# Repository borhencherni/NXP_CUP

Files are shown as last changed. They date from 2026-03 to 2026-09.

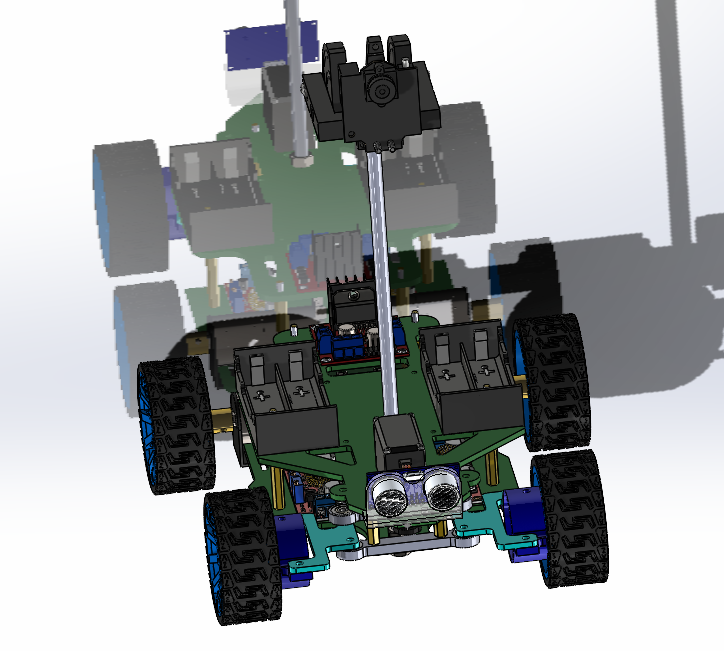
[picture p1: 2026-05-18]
Mechanical design of the robot.png

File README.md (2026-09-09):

**NXP Cup Robot**  
This repository contains the software, electronics, mechanical references, and documentation for the NXP Cup lane-following competition robot.  
   
 The current implementation is centered on two main embedded targets:  
- a Teensy 4.0 control unit that handles line tracking, steering, motor control, and telemetry generation  
- an ESP32 interface board that provides a web dashboard, manual drive controls, and live trajectory visualization  
**Project Overview 🤖**  
The robot is designed to follow a track as consistently and efficiently as possible while remaining debuggable during development.  
   
 The software is organized so that the core logic is separated into small header/source modules, making the control flow easier to maintain and inspect.  
   
 The goal of this document is to describe the robot, the role of each code part, and the current development phases in a way that matches the actual project structure.  
**System Architecture ⚙️**  
**Teensy 4.0 🧠**  
The Teensy is the main real-time controller. It is responsible for:  
- reading the Pixy2 line camera data  
- normalizing and fusing detected line vectors  
- computing a lookahead point for steering  
- applying PID-style steering correction  
- detecting lane sides and special line patterns  
- driving the motors and steering servo  
- reading the ultrasonic distance sensor  
- sending telemetry packets to the ESP32 over UART  
The Teensy code is organized into focused modules under NXPcup/include and NXPcup/src/teensy:  
- teensy_config.h for constants, pins, and tuning values  
- teensy_state.h and teensy_state.cpp for shared robot state  
- teensy_motors.h and teensy_motors.cpp for motor and servo output  
- teensy_sensors.h and teensy_sensors.cpp for ultrasonic sensing  
- teensy_vision.h and teensy_vision.cpp for Pixy2 processing and steering logic  
- main_teensy.cpp as the control entrypoint  
**ESP32 Interface 🌐**  
The ESP32 acts as the operator interface and telemetry gateway. It is responsible for:  
- receiving telemetry packets from the Teensy through UART  
- exposing a Wi-Fi access point  
- serving a browser-based control dashboard  
- sending manual drive commands back to the Teensy  
- drawing the robot trajectory in real time from received points  
The ESP32 code is organized into:  
- esp_config.h for UART and access point settings  
- esp_telemetry.h and esp_telemetry.cpp for packet parsing, point history, and command forwarding  
- esp_web.h and esp_web.cpp for the HTML interface and HTTP routes  
- main_esp.cpp as the entrypoint  
**Control Logic 🧭**  
The Teensy control loop follows a clear sequence:  
1. Read all Pixy2 line features  
2. Normalize line vector direction  
3. Fuse valid vectors into a single motion estimate  
4. Normalize the fused vector  
5. Compute an adaptive lookahead point  
6. Convert the lookahead error into steering correction  
7. Apply lane-side correction when only one side of the track is visible  
8. Clamp and smooth the servo command  
9. Drive the motors  
10. Send telemetry to the ESP32  
The telemetry packet format is:  
D,vx,vy,steeringangle,servoangle  
The ESP32 manual command format is:  
C,<command>  
Where the current commands are:  
- F for forward  
- B for backward  
- L for left  
- R for right  
- S for stop  
The current control strategy focuses on lane following and smooth steering.  
   
 The robot can be further developed by adding velocity regulation and speed profiling, in the style of the code asservissement vitesse approach, to keep the speed more stable across straights, curves, and transitions.  
**Phases Of Working 🔄**  
**1. Perception**  
The Pixy2 camera runs in line-tracking mode and the Teensy extracts track geometry from the visible vectors.  
   
 This phase focuses on identifying the path, rejecting noise, and understanding sharp turns, lane boundaries, and horizontal markers.  
**2. Motion Estimation**  
The detected vectors are filtered and fused into a single direction estimate.  
   
 A lookahead point is then computed so the robot can react smoothly on straights and more aggressively in curves.  
**3. Steering And Drive Control**  
The steering output is computed from the lookahead error and adjusted with PID-style terms.  
   
 The motor speed and servo angle are then constrained to keep motion stable.  
**4. Telemetry And Debugging**  
The Teensy sends live telemetry to the ESP32 so the robot can be observed while running.  
   
 This data includes vector direction, steering output, and servo angle.  
**5. Operator Interface**  
The ESP32 hosts a browser dashboard with manual drive buttons and a live trace of the robot path.  
   
 The LED status indicator changes color based on whether telemetry is being received.  
**6. Mechanical And Electrical Integration**  
The CAD, PCB, and wiring notes are used to assemble the chassis, sensors, drivetrain, and electronics reliably.  
   
 This phase ties the software to the physical robot.  
**Mechanical Part 🛠️**  
The mechanical part covers the chassis, steering, drivetrain, and mounting system.  
   
 These references are useful for assembly, servicing, and mechanical debugging.  
**Robot Assembly**  
**Mechanical Design**  
**Electrical Part ⚡**  
The electrical part covers the wiring, PCB layout, power distribution, and interface hardware.  
   
 These elements support the sensors, controller, motor driver, and communication links.  
**System Schematic**  
**PCB Routing**  
**PCB Overview**  
**Validation Videos 🎥**  
The following videos are used to validate different layers of the system during development:  
- video for the robot completing one lap.mp4 for the robot completing one lap  
- video for the robot stopping when detecting the box.mp4 for the robot stopping test  
**Pins And Hardware Notes 📌**  
Current Teensy pin usage:  
- motor inputs: 22, 23, 6, 7  
- servo output: 8  
- ultrasonic trigger: 18  
- ultrasonic echo: 19  
The project uses:  
- Teensy 4.0 as the controller  
- Pixy2 in line mode  
- steering servo  
- H-bridge motor driver  
- ultrasonic distance sensor  
- ESP32 for telemetry and control UI  
**Web Interface 🖥️**  
The ESP32 dashboard uses a dark industrial theme based on black, white, and #AA0000 red accents.  
   
 It includes:  
- forward, backward, left, right, and stop buttons  
- a circular ESP badge with a connection LED  
- live telemetry readouts  
- a black canvas with a white trail showing the robot path in real time  
**Web Interface Preview**  
**Software Layout 💻**  
The main source folders are:  
- NXPcup/src/teensy for the Teensy 4.0 control code  
- NXPcup/src/esp for the ESP32 dashboard and UART bridge  
- NXPcup/include for shared headers and configuration  
- NXPcup/lib for legacy or reusable helper sources  
- notes for pinout and power notes  
- Mécanique for CAD and mechanical references  
**Code Roles 🧩**  
The code is split so each module has a clear role in the robot:  
- main_teensy.cpp runs the full real-time control loop and coordinates perception, steering, drive output, and telemetry  
- teensy_vision.cpp handles Pixy2 processing, vector fusion, lane detection, and steering computation  
- teensy_motors.cpp converts high-level speed commands into motor outputs and servo control  
- teensy_sensors.cpp reads the ultrasonic sensor used for distance checking  
- teensy_state.cpp stores the shared robot state used by the other Teensy modules  
- main_esp.cpp initializes the ESP32 system and connects the web dashboard to UART telemetry  
- esp_telemetry.cpp parses telemetry packets, stores path points, and forwards manual commands  
- esp_web.cpp serves the browser interface, controls the buttons, and draws the live ride trace  
**Development Note 🚀**  
The robot can also be extended with velocity regulation and speed profiling in the style of code asservissement vitesse to stabilize motion across straights, curves, and transitions.  
**Power And Wiring Notes 🔌**  
The project notes indicate the following supply plan:  
- Teensy: 5V  
- camera: external 5V  
- servo: external 5V  
- motors: 12V  
- ultrasonic sensor: 3.3V  
- logic and power grounds must be shared where required  
**Build And Run 🏗️**  
The PlatformIO project is configured for the Teensy environment in NXPcup/platformio.ini.  
   
 Typical workflow:  
1. open the NXPcup folder in PlatformIO or VS Code  
2. build the Teensy environment  
3. upload to the Teensy board  
4. power the ESP32 and open the Wi-Fi dashboard  
5. watch the telemetry stream and path trace in the browser  
Example build command:  
cd NXPcup  
 platformio run -e teensy40  
   
**Resources 📚**  
- [Enseirb NXP Cup 2019 ](https://github.com/Enseirb-NXP-Cup-2019/cars/blob/master/src/Arduino/suivi_piste.ino "https://github.com/Enseirb-NXP-Cup-2019/cars/blob/master/src/Arduino/suivi_piste.ino")  
- [Enseirb NXP Cup 2019 website](https://github.com/Enseirb-NXP-Cup-2019/nxpcup.enseirb.github.io?tab=readme-ov-file "https://github.com/Enseirb-NXP-Cup-2019/nxpcup.enseirb.github.io?tab=readme-ov-file")  
- [Electromaker NXP Cup project](https://www.electromaker.io/project/view/nxp-cup-project "https://www.electromaker.io/project/view/nxp-cup-project")  
- [NXP-CUP-FINALS](https://github.com/aminebensaid66/NXP-CUP-FINALS "https://github.com/aminebensaid66/NXP-CUP-FINALS")  
**Notes 📝**  
This documentation reflects the current modularized Teensy and ESP32 codebase.  
   
 It is intended to help with debugging, maintenance, and competition preparation by keeping the code paths, hardware roles, and project assets in one place.  
   
   
 This work was done by the team members :  
   
 - Borhen CHERNI  
 - Mahmoud SOUABNI  
 - Meher LAHWAR

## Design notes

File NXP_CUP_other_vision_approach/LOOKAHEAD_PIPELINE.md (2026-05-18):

# From (vx, vy) to (px, py) — Lookahead Pipeline

## Context

The Pixy2 camera sees the line on the track and returns a set of vectors.
After filtering, fusing, and normalizing those vectors, we end up with a
single **unit vector (vx, vy)** that represents the direction of the line
ahead of the car.

The goal of this pipeline is to convert that direction into a **target point
(px, py)** in the camera frame — a point that the car should aim for.

---

## Step 1 — What is (vx, vy) exactly?

After `normalizeFusedVector()`, the vector (vx, vy) is a **unit vector**:

```
√(vx² + vy²) = 1   always
```

This means the length is always exactly 1. Normalization throws away the
length information and keeps only the **direction** of the line.

### What the values mean

```
vx =  0.0   → line goes perfectly straight up     → no horizontal component
vx =  1.0   → line goes perfectly horizontal right → maximum right turn
vx = -1.0   → line goes perfectly horizontal left  → maximum left turn

vy = -1.0   → line goes straight up (away from car) → normal forward direction
vy =  0.0   → line is perfectly horizontal           → extreme case
```

> In Pixy2 coordinates, y increases downward. So a line going away from
> the car (upward in the frame) has a negative vy after normalization.

### Geometric interpretation

Since (vx, vy) is a unit vector, it can be written as:
```
vx = cos(θ)
vy = sin(θ)
```
where θ is the angle of the line relative to the horizontal axis.

If you walk **1 unit** in the direction (vx, vy), you move exactly:
- `vx` units horizontally
- `vy` units vertically

---

## Step 2 — What is the lookahead distance L?

Instead of steering toward the nearest point on the line, we look **ahead**
by a distance L along the direction vector — like a driver looking further
down the road rather than at the front bumper.

L is a **fraction of the frame size** — a number between 0 and 1 that
represents what percentage of the frame we want to look ahead.

```
L = 0.4  →  look 40% of the frame ahead  (close, reactive)
L = 0.9  →  look 90% of the frame ahead  (far, smooth)
```

In actual pixels:
```
L × frameWidth  = L × 78  pixels of horizontal reach
L × frameHeight = L × 51  pixels of vertical   reach
```

---

## Step 3 — Adaptive lookahead (computing L)

L is not fixed — it adapts based on how curved the road is.

### Why adaptive?

- On a **straight line** → look far ahead (smooth, stable steering)
- On a **sharp turn**   → look close   (reactive, don't overshoot the corner)

### Computing curvature

```cpp
float curvature = fabsf(vx);
```

Since vx ∈ [-1, 1] after normalization:
- `vx = 0`  → line going straight → curvature = 0
- `vx = ±1` → line going sideways → curvature = 1

`fabsf` takes the absolute value because we only care about *how much*
curvature there is, not which direction (left or right).

### The interpolation formula

```cpp
L = L_MAX - curvature * (L_MAX - L_MIN);
```

Let's break this down. First compute the constant part:
```
L_MAX - L_MIN = 0.9 - 0.4 = 0.5
```

So the formula simplifies to:
```
L = 0.9 - curvature × 0.5
```

| curvature | L | meaning |
|---|---|---|
| 0.0 | 0.9 - 0×0.5 = **0.9** | straight → look far |
| 0.5 | 0.9 - 0.5×0.5 = **0.65** | medium turn |
| 1.0 | 0.9 - 1×0.5 = **0.4** | sharp turn → look close |

As curvature increases from 0 to 1, L decreases linearly from 0.9 to 0.4.
This is called **linear interpolation** — the output changes at a constant
rate as the input changes.

Visually:
```
curvature:  0 ──────────── 0.5 ──────────── 1
         L=0.9             0.65          L=0.4
         (far)                          (close)
```

---

## Step 4 — Computing the pixel displacement (step_x, step_y)

Now that we have the direction (vx, vy) and the lookahead distance L,
we compute how many pixels to move from the car's position.

```
step_x = vx × L × frameWidth
step_y = vy × L × frameHeight
```

### Reading the formula

Read it as two multiplications in sequence:

```
L × frameWidth  →  total pixels we want to travel
                   e.g. 0.75 × 78 = 58.5 pixels total

× vx            →  of those 58.5 pixels, how many go horizontally
                   e.g. × 0.3 = 17.5 pixels to the right
```

The same logic applies for step_y with frameHeight.

### Why multiply x and y by different frame dimensions?

The frame is **not square** (78 × 51 pixels). If we used the same scale
for both axes, a vector pointing at 45° in real life would appear at a
wrong angle in pixel space.

By multiplying x by `frameWidth` and y by `frameHeight` separately, we
correctly stretch the unit vector into the actual pixel coordinate space
of the camera frame.

Example with a 45° line:
```
vx = 0.707,  vy = -0.707   (45° diagonal, unit vector)
L  = 0.75

step_x = 0.707 × 0.75 × 78 = 41.4 pixels right
step_y = 0.707 × 0.75 × 51 = 27.1 pixels up
```

Notice step_x ≠ step_y even though vx = vy in magnitude — because 78 ≠ 51.

---

## Step 5 — Computing the target point (px, py)

The car is always at the **bottom center** of the frame:
```
car_x = frameWidth  / 2 = 78 / 2 = 39   (horizontal center)
car_y = frameHeight      = 51            (bottom of frame)
```

The target point is simply the car's position plus the pixel displacement:
```cpp
px = frameWidth  / 2.0f + vx * L * frameWidth;
py = frameHeight         + vy * L * frameHeight;
```

Which expands to:
```
px = 39 + step_x
py = 51 + step_y
```

### Concrete example

Line going slightly to the right:
```
vx =  0.30,  vy = -0.95   (mostly forward, slightly right)
L  =  0.75   (medium lookahead)

step_x =  0.30 × 0.75 × 78 =  17.6 pixels right
step_y = -0.95 × 0.75 × 51 = -36.4 pixels up

px = 39 + 17.6 = 56.6
py = 51 - 36.4 = 14.6
```

The target point is at (56.6, 14.6) — upper right area of the frame,
which makes sense for a slight right curve ahead.

Visual representation:
```
(0,0)─────────────────────(78,0)
  │                          │
  │       * (56.6, 14.6)     │  ← target point
  │      ↗                   │
  │     ↗  L steps            │
  │    ↗   along vector       │
  │   ↗                      │
(0,51)────────●──────────(78,51)
             (39,51) ← car position
```

---

## Step 6 — Why only px is used for steering

After computing (px, py), only **px** is passed to the PID controller:

```cpp
float error = px - frameWidth / 2.0f;
//          = 56.6 - 39
//          = 17.6
```

The error is the **horizontal deviation** of the target point from the
frame center:

```
error > 0  →  target is to the right  →  steer right
error < 0  →  target is to the left   →  steer left
error = 0  →  target is centered      →  go straight
```

`py` is not used because the steering only needs to know *left or right*,
not *how far ahead* the target point is. The lookahead distance already
did its job by influencing where the target point ended up horizontally.

---

## Summary of the full pipeline

```
(vx, vy)              unit vector, direction of the line
    │
    ▼
curvature = fabsf(vx) how curved is the road (0=straight, 1=sharp)
    │
    ▼
L = L_MAX - curvature × (L_MAX - L_MIN)   adaptive lookahead fraction
    │
    ▼
step_x = vx × L × frameWidth    pixel displacement from car position
step_y = vy × L × frameHeight
    │
    ▼
px = frameWidth/2  + step_x     target point in frame coordinates
py = frameHeight   + step_y
    │
    ▼
error = px - frameWidth/2       horizontal deviation → fed into PID
```

---

## Constants reference

| Constant | Value | Meaning |
|---|---|---|
| `L_MIN`  | 0.4 | Minimum lookahead (sharp turns) |
| `L_MAX`  | 0.9 | Maximum lookahead (straights) |
| `frameWidth`  | 78 px | Pixy2 line tracking frame width  |
| `frameHeight` | 51 px | Pixy2 line tracking frame height |

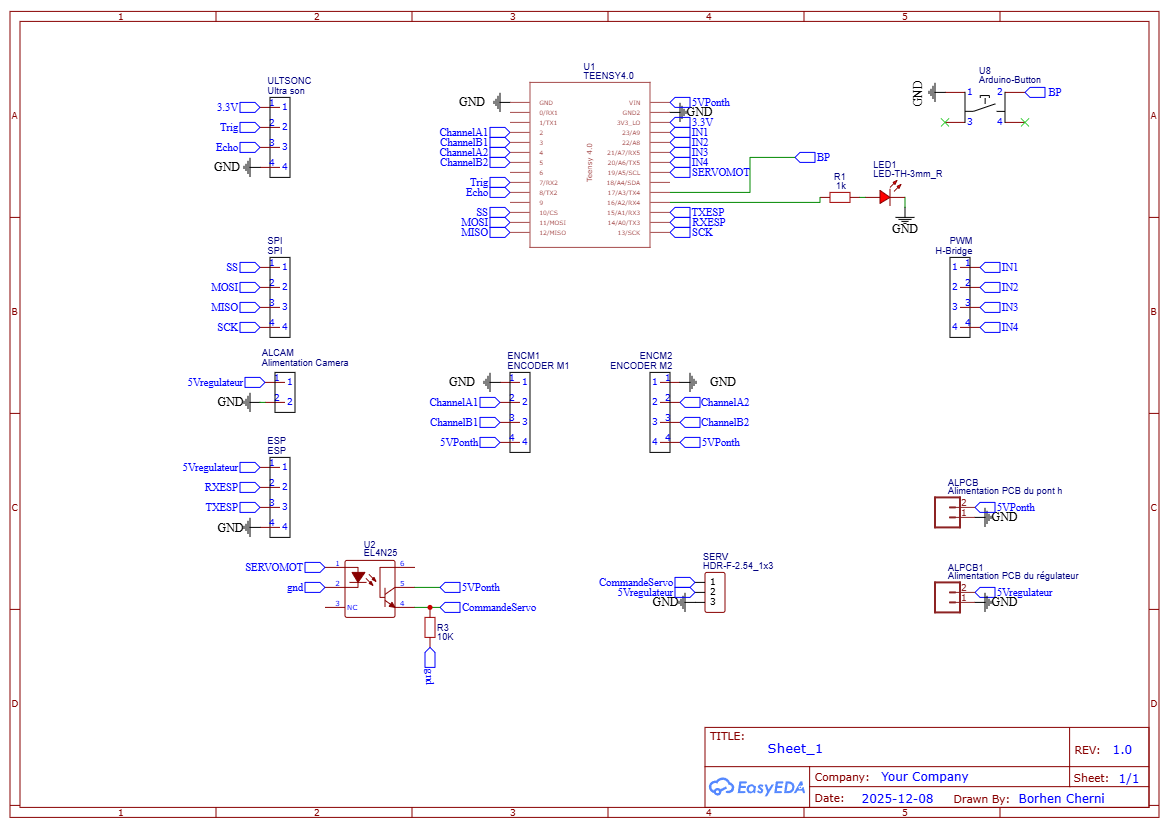
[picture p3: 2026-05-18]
Schematic_NXPCup.png

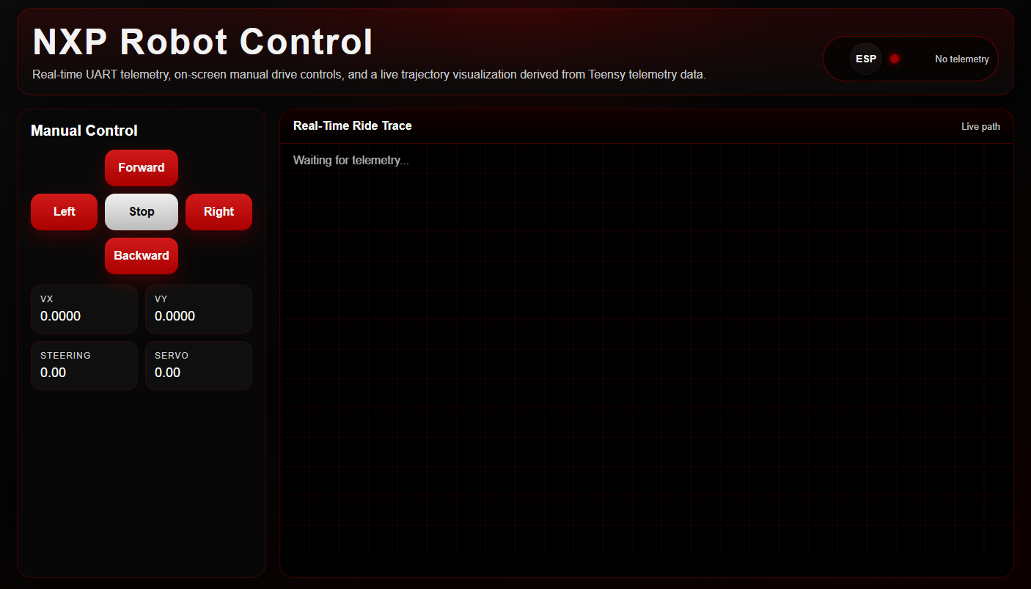
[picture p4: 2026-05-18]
webinterface.png

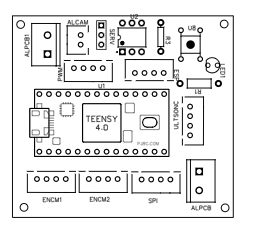
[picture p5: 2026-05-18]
PCB_NXPCup.png

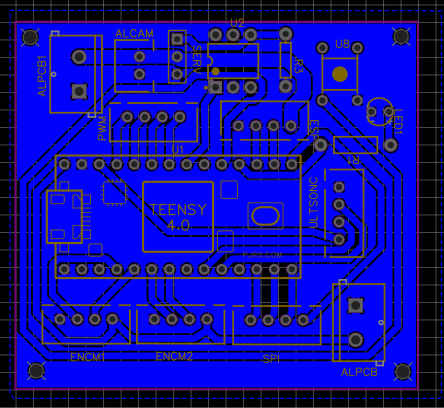
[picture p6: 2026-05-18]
Routing PCBNXP.png

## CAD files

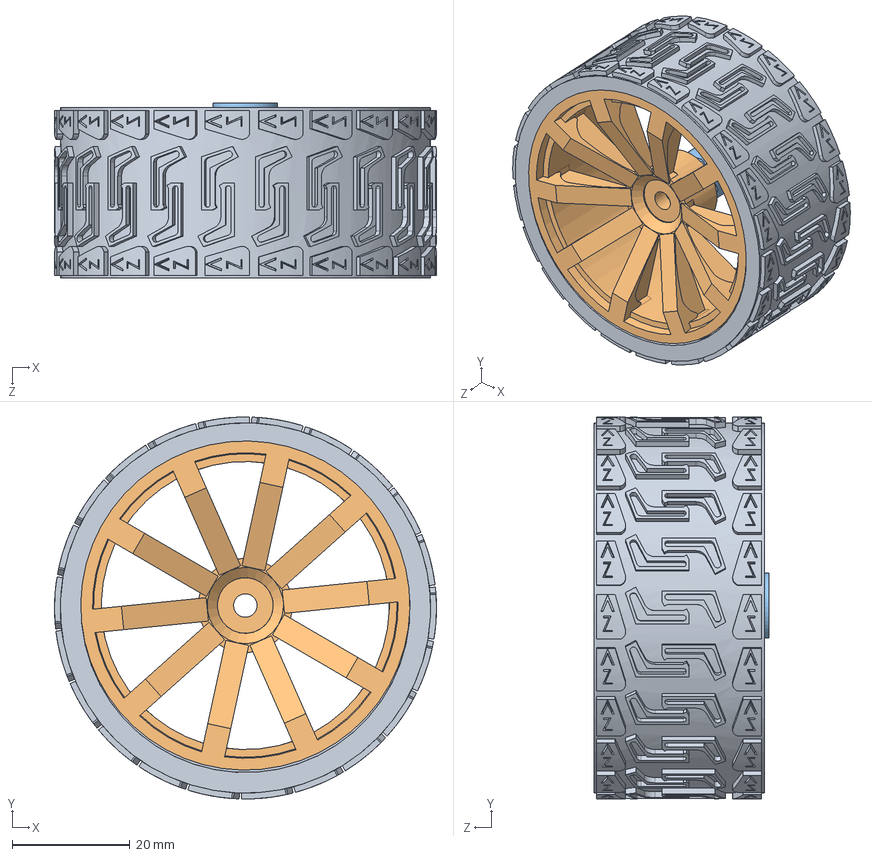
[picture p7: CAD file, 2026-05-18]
Mécanique/DAJA/blue_wheel_with_adapter.SLDASM
65.0 x 65.0 x 29.8 mm
65mm tire
blue_wheel_frame
motor_adapter

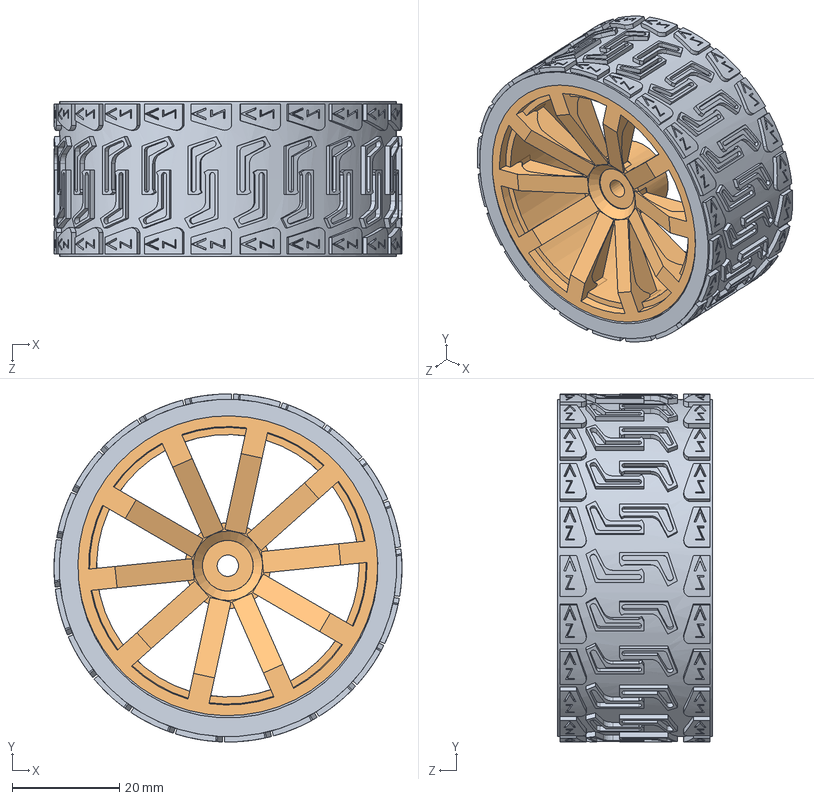
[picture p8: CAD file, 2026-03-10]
Mécanique/DAJA/blue_wheel_v1.SLDASM
65.0 x 65.0 x 29.0 mm
65mm tire
blue_wheel_frame

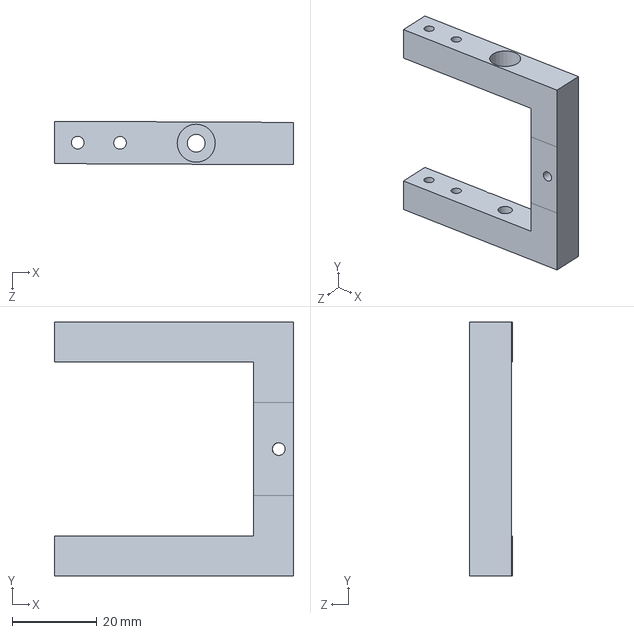
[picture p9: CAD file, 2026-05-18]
Mécanique/DAJA/Buggy/Buggy.step.SLDPRT
56.5 x 60.0 x 10.3 mm

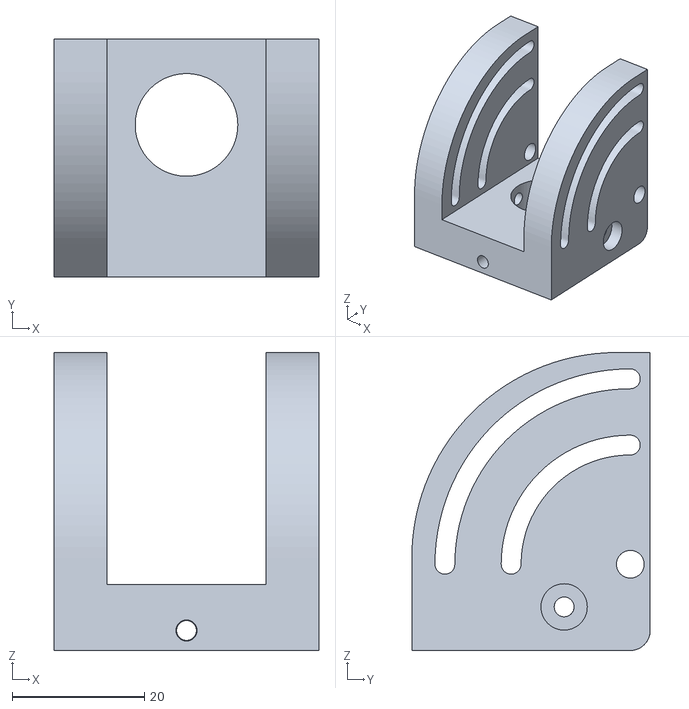
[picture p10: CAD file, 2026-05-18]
Mécanique/DAJA/Buggy/kit_finalfinal/STL/SlidingComponent.stl
40.0 x 36.0 x 45.0

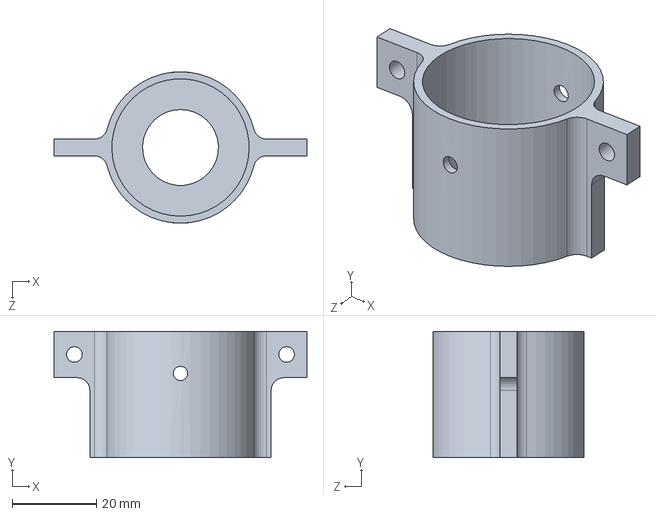
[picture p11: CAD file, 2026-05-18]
Mécanique/DAJA/cache_roulement.SLDPRT
60.0 x 30.0 x 35.9 mm

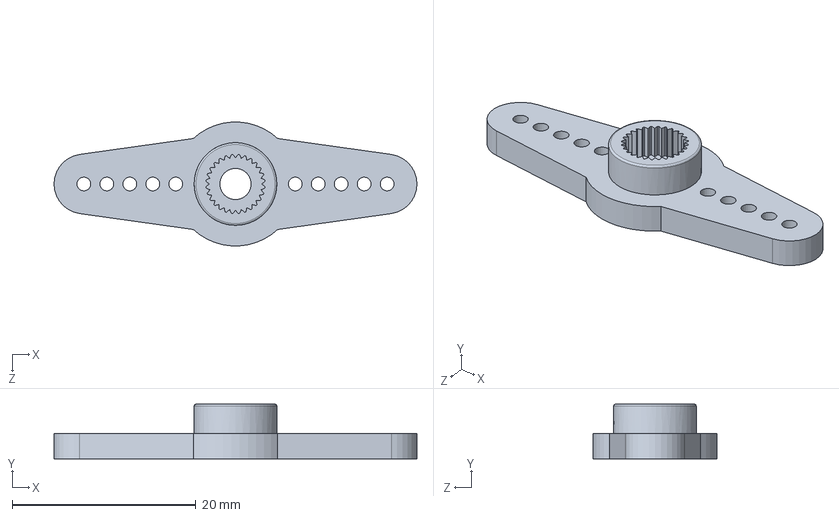
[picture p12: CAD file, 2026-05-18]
Mécanique/DAJA/mg-996r-servo-motor-1.snapshot.23/Parts/2-star horn.SLDPRT
39.5 x 5.95 x 13.5 mm

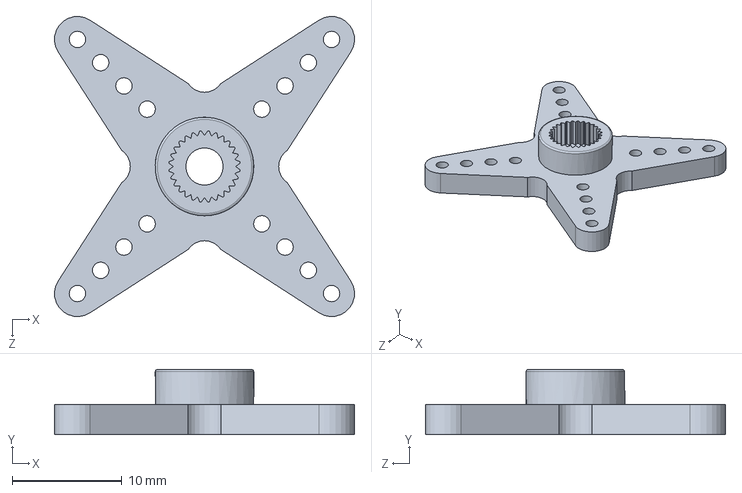
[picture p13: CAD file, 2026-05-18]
Mécanique/DAJA/Parts/4-star horn.SLDPRT
27.4 x 5.95 x 27.4 mm

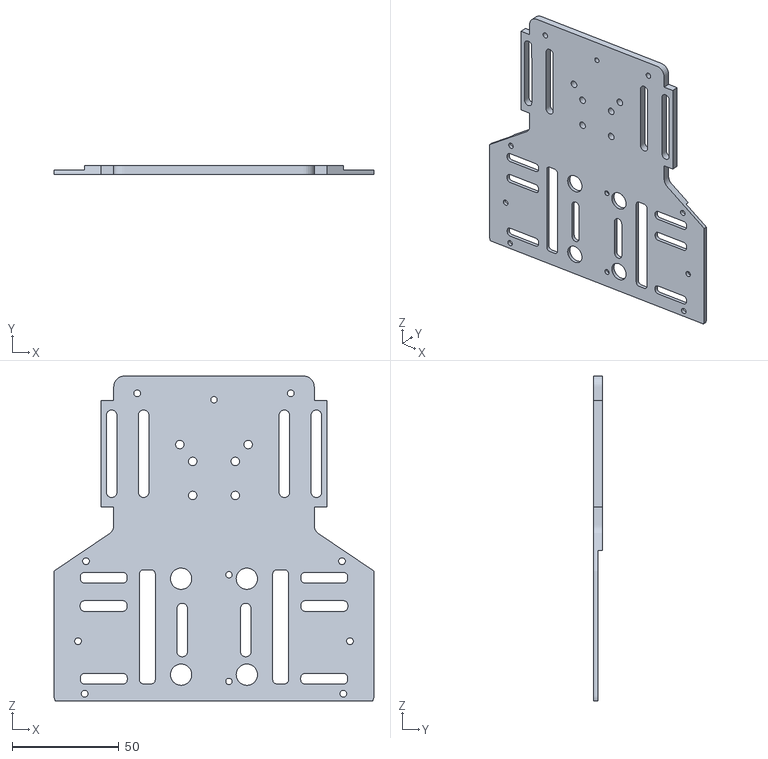
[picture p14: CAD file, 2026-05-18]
Mécanique/DAJA/Buggy/kit_finalfinal/STL/BottomPlateHalf2.stl
150.0 x 4.00 x 152.3

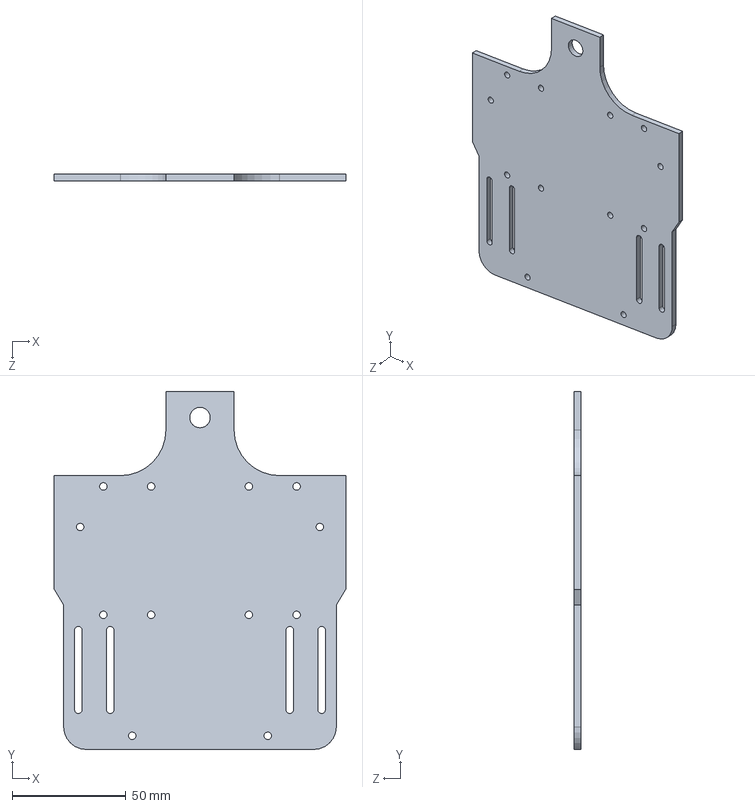
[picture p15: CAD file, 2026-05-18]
Mécanique/DAJA/buttom_part.SLDPRT
128.3 x 157.5 x 3.00 mm

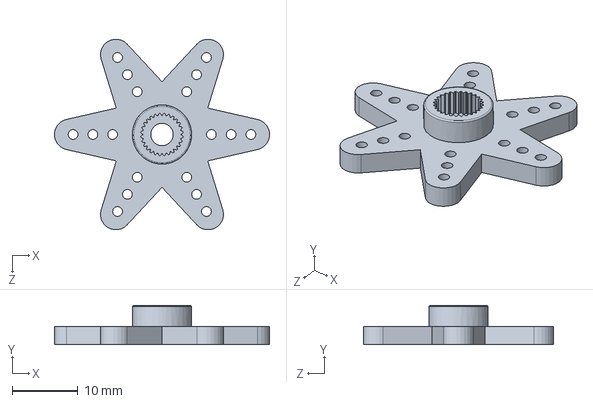
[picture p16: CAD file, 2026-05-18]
Mécanique/DAJA/Parts/6-star horn.SLDPRT
32.6 x 5.95 x 28.9 mm

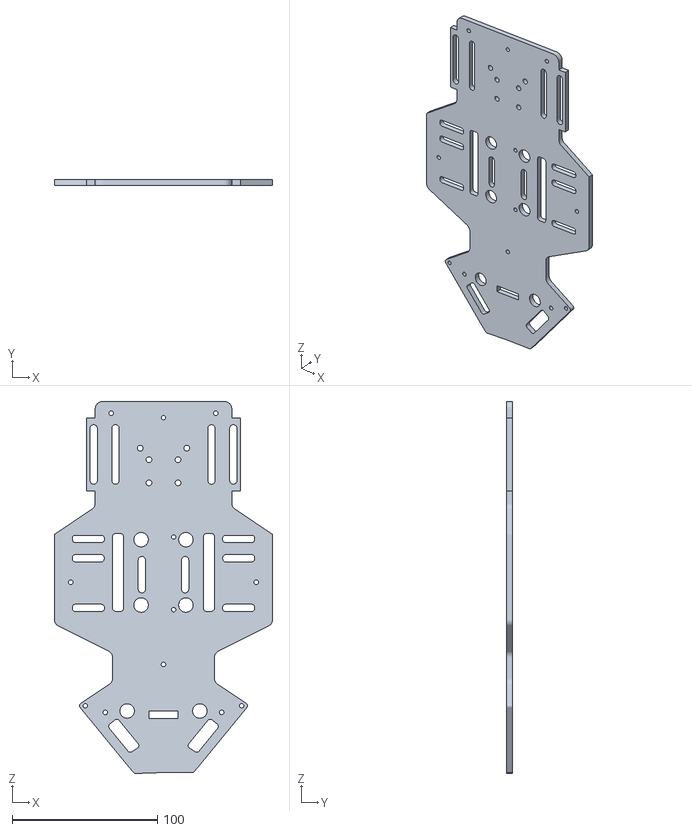
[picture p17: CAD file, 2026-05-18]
Mécanique/DAJA/Buggy/kit_finalfinal/STL/BottomPlate.stl
150.0 x 4.00 x 255.8

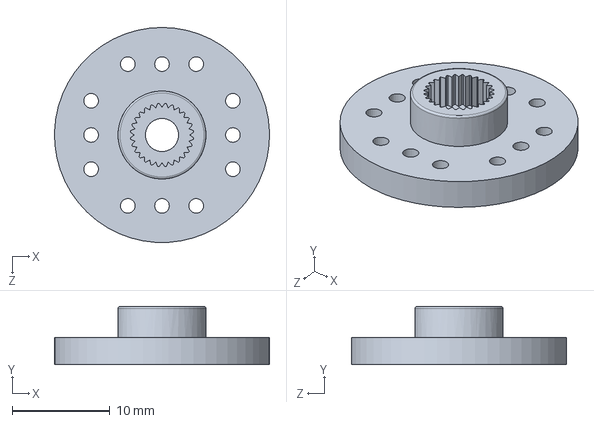
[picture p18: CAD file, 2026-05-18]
Mécanique/DAJA/mg-996r-servo-motor-1.snapshot.23/Parts/circular horn.SLDPRT
22.0 x 5.95 x 22.0 mm

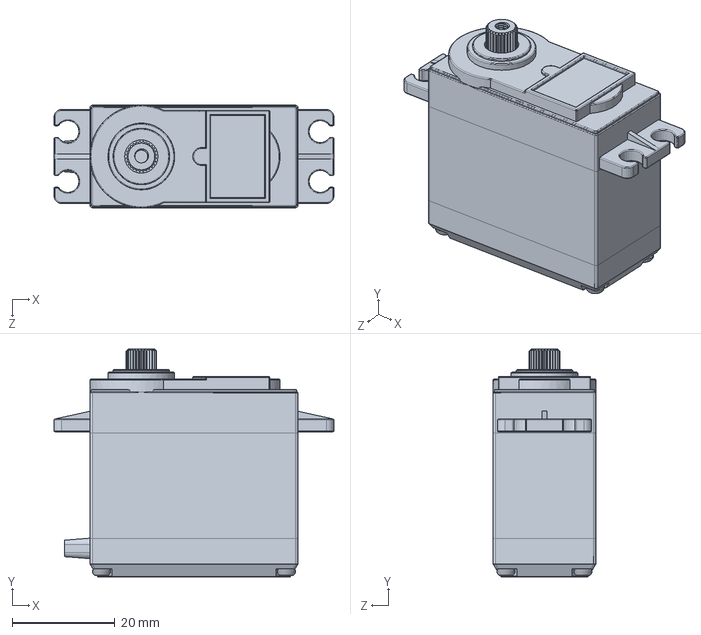
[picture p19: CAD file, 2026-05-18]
Mécanique/DAJA/Parts/MG996R Motor.SLDPRT
54.5 x 44.4 x 20.0 mm

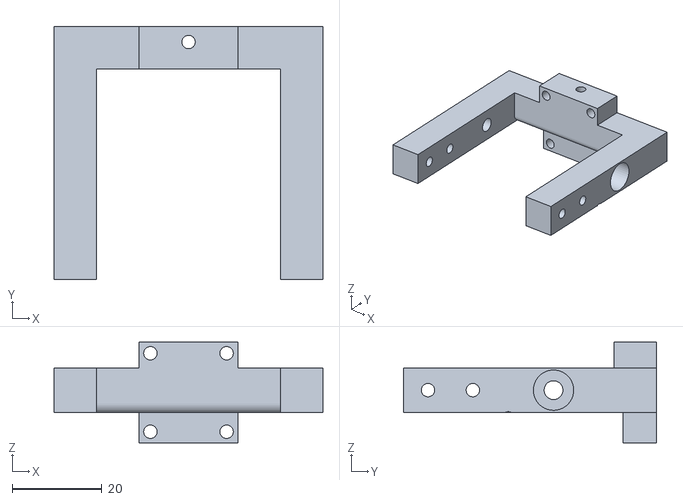
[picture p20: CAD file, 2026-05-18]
Mécanique/DAJA/Buggy/kit_finalfinal/STL/RotatingComponent.stl
60.0 x 56.5 x 22.5

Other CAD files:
Mécanique/DAJA/new_daja.SLDASM
Mécanique/DAJA/acc.SLDASM
Mécanique/DAJA/Assem3.SLDASM
Mécanique/DAJA/2-star-1 horn.SLDPRT
Mécanique/DAJA/65mm tire.SLDPRT
Mécanique/DAJA/92095A452_Button Head Hex Drive Screw.step.SLDPRT
Mécanique/DAJA/92095A455_Button Head Hex Drive Screw.step.SLDPRT
Mécanique/DAJA/BK-18650-PC4.stp
Mécanique/DAJA/Buggy/kit_finalfinal/STEP/Buggy.f3z
Mécanique/DAJA/Buggy/kit_finalfinal/STL/BottomPlateHalf1.stl
Mécanique/DAJA/Buggy/kit_finalfinal/STL/CameraFrame.stl
Mécanique/DAJA/Buggy/kit_finalfinal/STL/CameraHold.stl
Mécanique/DAJA/Buggy/kit_finalfinal/STL/FrontWheelAxle.stl
Mécanique/DAJA/Buggy/kit_finalfinal/STL/Linchpin.stl
Mécanique/DAJA/Buggy/kit_finalfinal/STL/MotorSideClamp.stl
Mécanique/DAJA/Buggy/kit_finalfinal/STL/OledBox.stl
Mécanique/DAJA/Buggy/kit_finalfinal/STL/PixyBox1.stl
Mécanique/DAJA/Buggy/kit_finalfinal/STL/PixyBox2.stl
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

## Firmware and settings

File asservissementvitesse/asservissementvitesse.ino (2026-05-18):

#include <Arduino.h>
#define PI 3.14159265358979323846
#define IN1 5
#define IN2 6
#define IN3 9
#define IN4 10
#define interruptPinRA 2
#define interruptPinRB 3
#define interruptPinLA 18
#define interruptPinLB 19


const float PWM_max = 255.0f;

float kpS_R = 0.8f;
float kiS_R = 0.2f;
float kdS_R = 0.01f;

float kpS_L = 0.8f;
float kiS_L = 0.2f;
float kdS_L = 0.01f;

float PWM_offset_R = 0.0f;
float PWM_offset_L = 0.0f;


// Target & measured speeds (mm/s)
float target_speed_R = 0.0f;
float target_speed_L = 0.0f;

float current_speed_R = 0.0f;
float current_speed_L = 0.0f;

float speed_integral_R = 0.0f;
float speed_integral_L = 0.0f;

float speed_derivative_R = 0.0f;
float speed_derivative_L = 0.0f;

float previous_speed_error_R = 0.0f;
float previous_speed_error_L = 0.0f;

float PWM_R = 0.0f;
float PWM_L = 0.0f;

unsigned long previous_speed_control_time = 0;

volatile long encoder_ticks_R = 620;
volatile long encoder_ticks_L = 620;

const float WHEEL_DIAMETER_MM = 65.0f;     
const int   TICKS_PER_REV     = 620;       

const float WHEEL_CIRCUMFERENCE = PI * WHEEL_DIAMETER_MM;
 
const float MM_PER_TICK = WHEEL_CIRCUMFERENCE / TICKS_PER_REV;


void resetSpeedPID()
{
    speed_integral_R = 0.0f;
    speed_integral_L = 0.0f;

    speed_derivative_R = 0.0f;
    speed_derivative_L = 0.0f;

    previous_speed_error_R = 0.0f;
    previous_speed_error_L = 0.0f;

    PWM_R = 0.0f;
    PWM_L = 0.0f;

    previous_speed_control_time = micros();
}

void interruptR() {
  if (digitalRead(interruptPinRA) == digitalRead(interruptPinRB)) {
    encoder_ticks_R--;
  } else {
    encoder_ticks_R++;
  }
}

void interruptL() {
  if (digitalRead(interruptPinLA) == digitalRead(interruptPinLB)) {
    encoder_ticks_L++;
  } else {
    encoder_ticks_L--;
  }
}



void setup()
{
    Serial.begin(115200);
    resetSpeedPID();
    pinMode(interruptPinRA, INPUT_PULLUP);
    pinMode(interruptPinRB, INPUT_PULLUP);
    pinMode(interruptPinLA, INPUT_PULLUP);
    pinMode(interruptPinLB, INPUT_PULLUP);

    pinMode(IN1, OUTPUT);
    pinMode(IN2, OUTPUT);
    pinMode(IN3, OUTPUT);
    pinMode(IN4, OUTPUT);

    attachInterrupt(digitalPinToInterrupt(interruptPinRA), interruptR, CHANGE);
    attachInterrupt(digitalPinToInterrupt(interruptPinLA), interruptL, CHANGE);
}


void loop()
{
    unsigned long now = micros();
    float dt = (now - previous_speed_control_time) * 1e-6f;

    target_speed_R = 200.0f; // mm/s
    target_speed_L = 200.0f;

    long ticks_R, ticks_L;
    noInterrupts();
    ticks_R = encoder_ticks_R;
    ticks_L = encoder_ticks_L;
    encoder_ticks_R = 0;
    encoder_ticks_L = 0;
    interrupts();

    float measured_speed_R = (ticks_R * MM_PER_TICK) / dt;
    float measured_speed_L = (ticks_L * MM_PER_TICK) / dt;

    current_speed_R = 0.8f * current_speed_R + 0.2f * measured_speed_R;
    current_speed_L = 0.8f * current_speed_L + 0.2f * measured_speed_L;




    if (dt <= 0.0f || dt > 0.1f)
        dt = 0.001f;


    float error = target_speed_R - current_speed_R;

    speed_derivative_R =
        speed_derivative_R * 0.999f +
        0.001f * (error - previous_speed_error_R) / dt;

    speed_integral_R += error * dt;

    previous_speed_error_R = error;

    PWM_R =
        PWM_offset_R +
        kpS_R * error +
        kdS_R * speed_derivative_R +
        kiS_R * speed_integral_R;

    PWM_R = (PWM_R > PWM_max) ? PWM_max :
            (PWM_R < -PWM_max) ? -PWM_max : PWM_R;

    PWM_R = (target_speed_R == 0.0f) ? 0.0f : PWM_R;

    
    if (PWM_R == PWM_max || PWM_R == -PWM_max)
        speed_integral_R -= 2.0f * error * dt;


    error = target_speed_L - current_speed_L;

    speed_derivative_L =
        speed_derivative_L * 0.999f +
        0.001f * (error - previous_speed_error_L) / dt;

    speed_integral_L += error * dt;

    previous_speed_error_L = error;
    previous_speed_control_time = now;

    PWM_L =
        PWM_L * 0.95f +
        0.05f * (
            PWM_offset_L +
            kpS_L * error +
            kdS_L * speed_derivative_L +
            kiS_L * speed_integral_L
        );

    PWM_L = (PWM_L > PWM_max) ? PWM_max :
            (PWM_L < -PWM_max) ? -PWM_max : PWM_L;

    PWM_L = (target_speed_L == 0.0f) ? 0.0f : PWM_L;

    if (PWM_L == PWM_max || PWM_L == -PWM_max)
        speed_integral_L -= 2.0f * error * dt;



    Serial.print("PWM_R: ");
    Serial.print(PWM_R);
    Serial.print(" | PWM_L: ");
    Serial.println(PWM_L);

    delay(5); 
}

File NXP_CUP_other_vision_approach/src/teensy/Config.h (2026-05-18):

#pragma once

// ─── Pin definitions ──────────────────────────────────────────────────────────
#define IN1 6
#define IN2 7
#define IN3 22
#define IN4 23

#define Servo_PIN         17
#define Channel_A_LEFT    2
#define Channel_B_LEFT    3
#define Channel_A_RIGHT   4
#define Channel_B_RIGHT   5

// ─── Pixy2 frame dimensions ───────────────────────────────────────────────────
// The Pixy2 produces 317 px wide images in this configuration.
// frameHeight scales proportionally: 317 / 78 * 51 ≈ 207 px.
// The Pixy2 library exposes pixy.frameWidth / pixy.frameHeight at runtime;
// these defines are only used where a compile-time constant is unavoidable.
#define FRAME_WIDTH       317
#define FRAME_HEIGHT      207

// ─── Pixy2 aspect-ratio correction ───────────────────────────────────────────
// The ratio is derived from the sensor's physical FOV, not its resolution,
// so it stays the same regardless of resolution mode.
#define SCALE_Y(y)        ((y) * 1.53f)

// ─── Vector filtering ─────────────────────────────────────────────────────────
// MIN_VECTOR_LEN scales with frame width: 10 * (317/78) ≈ 40 px.
// Keeps the same physical angular span filtered at the new resolution
#define MIN_VECTOR_LEN    10.0f

// Angle threshold is purely geometric — does not depend on resolution.
#define MIN_TRACK_ANGLE   5.0f

// ─── Lookahead ────────────────────────────────────────────────────────────────
#define L_MIN             0.3f
#define L_MAX             0.7f

// ─── Steering PID gains ───────────────────────────────────────────────────────
#define KP                3.0f
#define KI                0.0f
#define KD                0.0f
#define I_MAX             10.0f

// ─── Servo ────────────────────────────────────────────────────────────────────
#define SERVO_CENTER      90
#define SERVO_MIN         60
#define SERVO_MAX         120

// ─── Low-pass filter ─────────────────────────────────────────────────────────
#define LPF_ALPHA         0.75f

// ─── Speed PID gains ─────────────────────────────────────────────────────────
#define KP_S              2.0f
#define KI_S              0.0f
#define KD_S              0.0f
#define I_MAX_S           15.0f

// ─── Encoder ─────────────────────────────────────────────────────────────────
#define nb_t_p_rot        22
#define SPEED_PERIOD_MS   5

// ─── Steering PID virtua&l-triangle constant ───────────────────────────────────
// STEERING_PIXEL_SCALE converts a pixel error into a steering angle via atan2.
// It must scale with frame width so the same real-world angular error produces
// the same steering output regardless of resolution.
// Previous value was 40 for a 78 px frame:  40 * (317 / 78) ≈ 163
#define STEERING_PIXEL_SCALE  163.0f

// ─── Frame centre (compile-time reference) ────────────────────────────────────
// 317 / 2 = 158.5.  Most code reads pixy.frameWidth/2 dynamically at runtime.
#define SCREEN_CENTER_X       158.5f

// ─── Track geometry ───────────────────────────────────────────────────────────
// Used when only ONE line is visible to estimate the lane centre.
//
// Calibration (do this once on the real track):
//   1. Place the car centred on the track.
//   2. Open Serial monitor; read leftX and rightX.
//   3. Set TRACK_WIDTH_PX = rightX - leftX.
//
// Starting estimate scaled from old value:  45 * (317 / 78) ≈ 183 px.
#define TRACK_WIDTH_PX        215

// ─── Intersection handling ────────────────────────────────────────────────────
// Duration the robot drives straight after a crossing is detected.
// Resolution-independent (time-based).
#define INTERSECTION_HOLD_MS  1500UL

// Continuity filter: max head-position drift between frames to still be
// considered the same line. Scaled: 22 * (317/78) ≈ 89 px.
#define CONTINUITY_THRESHOLD_PX  89.0f

// ─── Adaptive speed ──────────────────────────────────────────────────────────
#define BASE_SPEED           200    // PWM on a straight
#define MIN_SPEED            150    // PWM in the tightest turn
#define INTERSECTION_SPEED   0    // PWM while crossing an intersection

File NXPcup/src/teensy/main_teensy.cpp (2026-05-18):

#include <Arduino.h>

#include "teensy_config.h"
#include "teensy_motors.h"
#include "teensy_sensors.h"
#include "teensy_state.h"
#include "teensy_vision.h"

static String espCommandBuffer;

static void sendTelemetry(float vx, float vy, float steeringAngle, float servoAngle)
{
  Serial2.print("D,");
  Serial2.print(vx, 4);
  Serial2.print(',');
  Serial2.print(vy, 4);
  Serial2.print(',');
  Serial2.print(steeringAngle, 2);
  Serial2.print(',');
  Serial2.println(servoAngle, 2);
}

static void applyManualCommand(char command)
{
  switch (command)
  {
    case 'F':
      runMotors(120, 120);
      break;
    case 'B':
      runMotors(-120, -120);
      break;
    case 'L':
      runMotors(90, 120);
      break;
    case 'R':
      runMotors(120, 90);
      break;
    case 'S':
    default:
      runMotors(0, 0);
      break;
  }
}

static void processEspCommands()
{
  while (Serial2.available())
  {
    char c = Serial2.read();

    if (c == '\n')
    {
      espCommandBuffer.trim();
      if (espCommandBuffer.startsWith("C,"))
      {
        char command = espCommandBuffer.charAt(2);
        manualCommand = command;
        manualCommandUntil = millis() + 300;
        if (command == 'S')
        {
          manualCommandUntil = millis();
        }
      }
      espCommandBuffer = "";
    }
    else
    {
      espCommandBuffer += c;
    }
  }
}

static char manualCommand = 'S';
static unsigned long manualCommandUntil = 0;

void setup() {
  Serial.begin(115200);
  Serial2.begin(115200);
  Vision_Init();
  Motors_Init();
  Sensors_Init();
  startTime = millis();
}

void loop() {
  unsigned long now = millis();
  if (lastTime != 0 && (now - lastTime) < CONTROL_PERIOD_MS)
    return;

  float dt = (lastTime == 0) ? (CONTROL_PERIOD_MS / 1000.0f) : ((now - lastTime) / 1000.0f);
  if (dt <= 0.0f || dt > 0.5f) dt = CONTROL_PERIOD_MS / 1000.0f;
  lastTime = now;

  pixy.line.getAllFeatures();

  normalizeVectors();
  float vx, vy;
  fusedVector(vx, vy); 
  normalizeFusedVector(vx, vy);
  float px, py;
  lookaheadPoint(vx, vy, px, py);
  float steering = computeSteering(px, dt);
  detectLaneSides();

  // Step 2: update dash detection
  /*updateDashDetection();

  // Step 3: check finish line
  if (detectFinishLine())
  {
    runMotors(0, 0);
    servo.write(SERVO_CENTER);

    Serial.println("FINISH LINE DETECTED");

    while (1);
  }*/
  float laneCorrection = 0.0f;
  float strength = fabsf(vx); // curvature factor

  if(hasRight && !hasLeft)
  {
    laneCorrection = -LEFT_GAIN * (0.5f + strength);
  }
  else if(hasLeft && !hasRight)
  {
    laneCorrection = RIGHT_GAIN * (0.5f + strength);
  }

  // Apply correction ONCE
  steering += laneCorrection;

  // THEN constrain
  steering = constrain(steering, -40.0f, 40.0f);
  if (fabsf(steering) < STEERING_DEADBAND)
      steering = 0.0f;

  if(fabsf(vx) < 0.05f && vy > 0.9f)
  {
  steering = 0.0f;
  }
  float servoAngle = SERVO_CENTER + steering;
  servoAngle = constrain(servoAngle, SERVO_MIN, SERVO_MAX);
  float step = constrain(servoAngle - lastSteeringAngle, -MAX_SERVO_STEP, MAX_SERVO_STEP);
  servoAngle = lastSteeringAngle + step;
  lastSteeringAngle = servoAngle;
  Serial.print("Steering: ");
  Serial.print(steering); 
  Serial.print(" | Servo Angle: ");
  Serial.println(servoAngle);

  servoBuffer[servoIndex] = servoAngle;
  servoIndex++;

  if(servoIndex >= SERVO_FILTER_SIZE)
  {
    servoIndex = 0;
    bufferFilled = true;
  }

  // Use filtered value only when buffer is ready
  float filteredServo = servoAngle;

  if(bufferFilled && !isSharpTurn(steering))
  {
  filteredServo = computeMedian(servoBuffer, SERVO_FILTER_SIZE);
  }
  servo.write((int)filteredServo);
  float turnFactor = fabsf(steering) / 50.0f; // normalize 0 → 1

  int speed = MOTOR_SPEED * (1.0f - 0.6f * turnFactor); 

  speed = constrain(speed, 180, MOTOR_SPEED);

  processEspCommands();
  if (manualCommandUntil > millis())
  {
    applyManualCommand(manualCommand);
  }
  else
  {
    runMotors(120, 120);
  }

  sendTelemetry(vx, vy, steering, servoAngle);

  if(millis()-startTime>13000){
    speed=110;
    runMotors(120, 120);
    float distance = readUltrasonic();
    if (distance > 15 && distance < 30){
      runMotors(0, 0);
      while(1);
    }
  }
}

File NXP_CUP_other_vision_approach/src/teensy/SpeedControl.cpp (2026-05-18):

#include "SpeedControl.h"
#include "Config.h"
#include <Arduino.h>
//public
void SpeedControl::setSpeed(int L_speed, int R_speed){
    unsigned long now = millis();

    if (_previous_time == 0) { _previous_time = now; return; }
    if (now - _previous_time < SPEED_PERIOD_MS) return;

    float dt = (now - _previous_time) / 1000.0f;
    _previous_time = now;

    _target_speed_left = L_speed;
    _target_speed_right = R_speed;

    compute_current_speed(dt);
    float PID_speed_left = compute_PID_speed(_current_speed_left, _target_speed_left,_integralErrorLeft, _lastErrorLeft , dt);
    float PID_speed_right = compute_PID_speed(_current_speed_right, _target_speed_right, _integralErrorRight, _lastErrorRight , dt);
    runMotors(constrain(PID_speed_left,0,255),constrain(PID_speed_right,0,255));
}

// private
void SpeedControl::compute_current_speed(float dt){
    
    noInterrupts();
    int tl = _ticks_left;  _ticks_left = 0;
    int tr = _ticks_right; _ticks_right = 0;
    interrupts();
    _current_speed_left = ((float)tl/ _nb_ticks_PR)*(60.0f)/ (dt);
    _current_speed_right = ((float)tr / _nb_ticks_PR)*(60.0f)/ (dt); 
   
}

float SpeedControl::compute_PID_speed(float current_speed, float target_speed,float& IntegralError, float& lastError, float dt){
    float Kp = KP_S;
    float Ki = KI_S;
    float Kd = KD_S;
    float error = target_speed - current_speed;
    IntegralError = constrain(IntegralError + (error * dt), -I_MAX_S, I_MAX_S);
    float derivativeError = error - lastError;
    float output = Kp * error + Ki * IntegralError + Kd * (derivativeError/dt);
    lastError = error;
    return output;
}

void SpeedControl::runMotors(int left_PWM, int right_PWM){
    if(left_PWM < 0){
        analogWrite(IN1, 0);
        analogWrite(IN2, -left_PWM);
    }
    else{
        analogWrite(IN1, left_PWM);
        analogWrite(IN2, 0);
    }
    if(right_PWM < 0){
        analogWrite(IN3, 0);
        analogWrite(IN4, -right_PWM);
    }
    else{
        analogWrite(IN3, right_PWM);
        analogWrite(IN4, 0);
    }
    
}

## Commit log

2026-03-10 Initial commit NXP cup
    [2-star-1 horn.SLDPRT, 65mm tire.SLDPRT, 92095A452_Button Head Hex Drive Screw.step.SLDPRT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]
2026-04-02 awel code bel pcb jdida
2026-04-08 tarki7 bel servo buffer
2026-05-18 Final updates
    [2-star horn.SLDPRT, 4-star horn.SLDPRT, 6-star horn.SLDPRT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]
